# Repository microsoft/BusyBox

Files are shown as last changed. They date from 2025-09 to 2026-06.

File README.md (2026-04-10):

# BusyBox: Benchmarking Affordance Generalization

BusyBox is a physical 3D-printable device for benchmarking affordance generalization in robot foundation models.

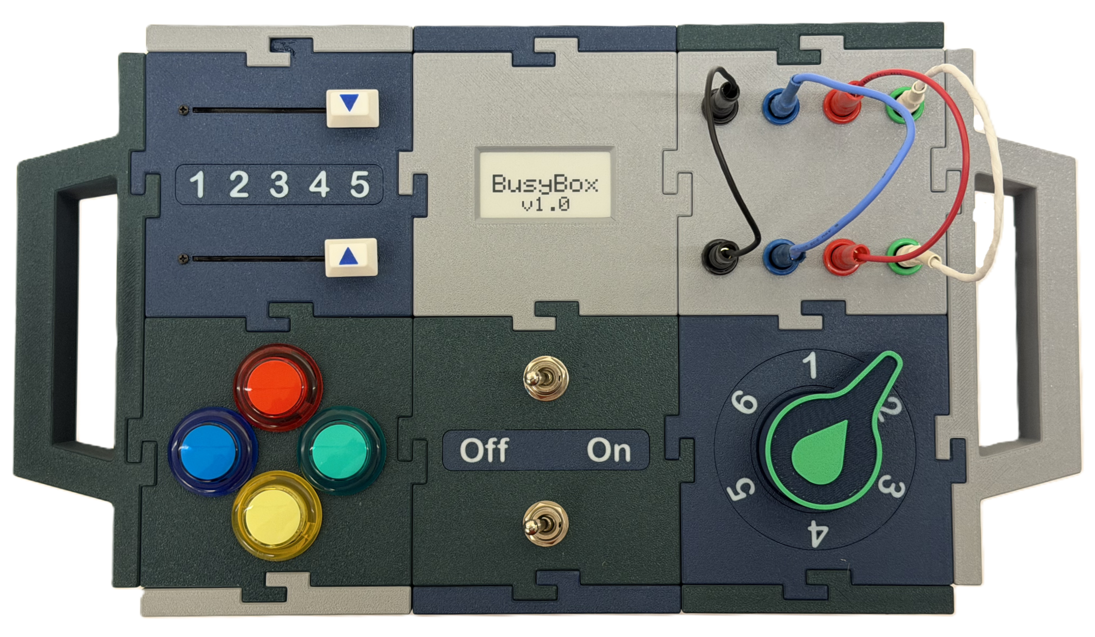
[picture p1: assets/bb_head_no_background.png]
busybox_assembled


It features

 - Modular design with 6 interchangeable modules (buttons, switches, sliders, wires, knob, and display)  
 - Open-source CAD files and bill of materials for easy reproduction  
 - Optional electronics and Raspberry Pi instrumentation for automated state logging  
 - Reconfigurable setups enabling systematic evaluation of generalization  
 - A language-annotated dataset of 1000+ demonstration trajectories oof BusyBox affordances  

Please check out our [website](https://microsoft.github.io/BusyBox/) for more details.

## BusyBox assembly instructions

For fully building a instrumented BusyBox capable of state logging, see the [BOM](BOM.md).

First print the BusyBox following [Printing Instructions](cad/printing_instructions.md) with details on files to print and any details on print settings.

## Electronic Assembly:

TODO: add instructions on how to assemble electronics with pictures

## Firmware Flashing:

Instructions for flashing the Arduino Nano's firmware: [Flashing Firmware](devices/flashing_firmware.md)

## Data Collection

See [Data Collection](assets/taskbox_data_collection.docx) for details on our data collection methodology.

### Recording Episodes with Aloha

The `robots/aloha/` directory contains a complete data recording pipeline for collecting teleoperated demonstrations using the [Aloha](https://github.com/tonyzhaozh/aloha) bimanual robot.

#### Prerequisites

- Aloha robot hardware (leader + follower arms) set up and calibrated
- USB foot pedal for episode control
- (Optional) Instrumented BusyBox with MQTT bridge for state logging

#### Quick Start

```bash
pip install -r requirements.txt
python robots/aloha/record_busybox_episodes.py
```

#### Foot Pedal Controls

| Pedal | Action |
|---|---|
| Left | Start recording |
| Middle | Stop and save episode / Refresh task prompt |
| Right | Pause/resume teleop / Reject recording |

#### Configuration

Edit `robots/aloha/utils/config.py` to set:
- `dataset_dir` — where episodes are saved
- `camera_names` — which cameras to record
- `using_instrumented_busybox` — enable MQTT state logging

#### Episode Data Format (HDF5)

Each episode is saved as an HDF5 file with:
- `/observations/qpos` — joint positions (14,) per timestep
- `/observations/qvel` — joint velocities (14,)
- `/observations/effort` — joint torques (14,)
- `/observations/images/{cam_name}` — JPEG-compressed camera frames
- `/action` — leader arm joint commands (14,)
- `/observations/timestamp`, `/action_timestamp` — timing data

#### Utility Scripts

| Script | Purpose |
|---|---|
| `scripts/count_episodes_collected_today.py` | Count episodes recorded in the current session |
| `scripts/busybox_calibration.py` | BusyBox sensor calibration |
| `scripts/visualize_hdf5.ipynb` | Visualize recorded episode data |
| `robots/aloha/eval_rollouts.py` | Evaluate policy rollouts |

### Raspberry Pi MQTT Bridge

For instrumented BusyBox setups, the `devices/pi_sw/` directory contains the MQTT bridge that runs on the Raspberry Pi:

```bash
# On the Raspberry Pi
pip install pyserial paho-mqtt
python devices/pi_sw/mqtt_bridge.py --broker-host <MQTT_BROKER_IP>
```

See [Flashing Firmware: Installing MQTT on the Pi](devices/flashing_firmware.md#6-installing-mqtt-on-the-pi) for setup details.

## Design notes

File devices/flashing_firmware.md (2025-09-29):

# Setting up Raspberry Pi Zero W for flashing BusyBox firmware

### 1. Install OS
Install [Raspberry Pi OS (64-bit)](https://www.raspberrypi.com/software/operating-systems/) on [Pi Zero 2 W](https://www.raspberrypi.com/products/raspberry-pi-zero-2-w/). 

### 2. Acquire Hardware
required hardware:
 - Enough USB hubs to flash all BusyBox Modules desired (for 6 modules, this requires 6 Nanos and 2 4-port USB Hubs).
 - internet connection for Pi Zero 2 W

### 3. Install and Initialize Arduino CLI

install
```bash
curl -fsSL https://raw.githubusercontent.com/arduino/arduino-cli/master/install.sh | sh
sudo mv bin/arduino-cli /usr/local/bin/
rm -rf bin
```

initialize 
```bash
arduino-cli config init
arduino-cli core update-index
arduino-cli core install arduino:avr
# e-ink display drivers
arduino-cli lib update-index
arduino-cli lib install "GxEPD2"
```

### 4. Build and Upload firmware code to Arduinos

Plug in USB Hubs to the Pi Zero 2 W. This requires one USB Hub to be daisy chained to the other.

Plug in the targeted number of Arduinos to the Pi Zero 2 W's USB Hubs.

```bash
cd BusyBox/devices
ls /dev/ttyUSB* -la  # view connected Arduino Nanos
nano device_build_targets.yaml  # edit device ports and module targets as needed
./build_all.sh
./upload_all.sh
```

### 5. Verify firmware

View serial output of arduinos:
```bash
# replace /dev/ttyUSB0 with the device you want to view
screen /dev/ttyUSB0 9600
# Exit: `Ctrl+A` then `K` → `Y`.
```

If using the E-ink display module, send e-ink commands:
```bash
# assuming /dev/ttyUSB5 corresponds to the e-ink module
stty -F /dev/ttyUSB5 9600 cs8 -cstopb -parenb
echo -e "1:Hello\n" > /dev/ttyUSB5  # set top line
echo -e "2:World\n" > /dev/ttyUSB5  # set bottom line
```

test port identification of modules
```bash
cd BusyBox/devices
python test_identify_arduinos.py
```

this should return:
```
Detected Arduino modules:
PORT          MODULE
------------  --------------------
/dev/ttyUSB0  buttons_module
/dev/ttyUSB1  knob_module
/dev/ttyUSB2  sliders_module
/dev/ttyUSB3  switches_module
/dev/ttyUSB4  wires_module
/dev/ttyUSB5  e-ink_display_module
```

### 6. Installing MQTT on the pi
```bash
sudo apt update
sudo apt install -y mosquitto mosquitto-clients
sudo systemctl enable mosquitto
sudo systemctl start mosquitto
# Check status:
systemctl status mosquitto

sudo apt install python3-paho-mqtt
```

running the mqtt bridge
```bash
cd BusyBox/devices/pi_sw
python mqtt_bridge.py --broker-host localhost  # MQTT broker on pi
python mqtt_bridge.py --broker-host 10.137.70.35  # MQTT broker on other PC

# command the e-ink display:
mosquitto_pub -t busybox/eink/cmd -m "1:BusyBox Demo"
mosquitto_pub -t busybox/eink/cmd -m "2:Ready!"

# listen to published topic chatter
mosquitto_sub -h localhost -t 'busybox/buttons/state' -v  # replace `buttons` with desired state
```

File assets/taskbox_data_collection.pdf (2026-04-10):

# Taskbox Data Collection Guide

There are surprisingly so many ways to push a button, pull a wire, and move a slider. Variations include trajectory taken, which arm was used, starting point, ending point, movement speed, etc. This guide is meant to unify how data is collected so models have high quality demonstrations useful for finetuning.

This guide is specifically relating to collecting data by teleoperating the Mobile Aloha to collect demonstrations on accomplishing tasks on the taskbox.

General rules and task specific rules for robot operators follow.

## General rules

1. Be efficient with movement. Demonstrations should take no longer than 15 seconds.
2. Keep moving. Demonstrations should be active, only remain still when something dynamic is happening (i.e. dropping a wire).
3. End a session when task has been completed. There is no need to return to a neutral position.
4. Start from different initial positions before recording. These starting positions fall between the starting home position and somewhere above the box.
5. Ensure both wrist cameras have a view of the task at hand.
6. Follow pre-recording instructions that set the initial state of the taskbox, the pose of the taskbox, and the starting position of the arm.

## Specific rules

Here is the taskbox:

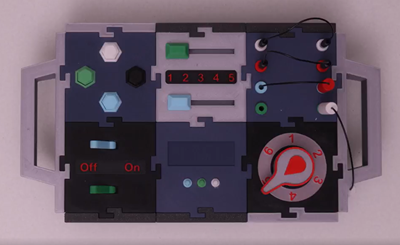
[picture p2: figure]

from top left to bottom right the modules are as follows: buttons, slider, wires, switches, display, and knob

Button Module

With grippers closed, move to press the button with one gripper and have the other arm’s camera viewing the action. End recording just after button is released and the gripper is a few inches above the button. If the button press was missed, retry at most once before ending the recording.

Slider Module

With grippers closed, move the slider by pushing it one direction or another. If the value is overshot, correct the overshoot and end the recording. The other arm’s camera should have visual.

Wires Module

When pulling a wire, only pull the bottom terminal or the right terminal based on module orientation. After pulling the wire out of the terminal, leave the other end in place.

When inserting a wire, it may be required to move the wire in a more favorable position before recording so the demonstration does not exceed 15 seconds.

Switch module

Brace the box by holding the handle with one gripper and move the switch to the desired position with the other gripper.

Knob Module

With grippers closed, one gripper will nudge the knob until it is in the desired position and the other will view with its camera. If the target is overshot, just nudge in the other direction.

## Pre recording instructions

Before recording an episode a prompt will ask the operator to move the robot to a certain position and angle on the table, set the state of sliders, wires, switches, and knob, and request a general starting position for the arm between home position and taskbox.

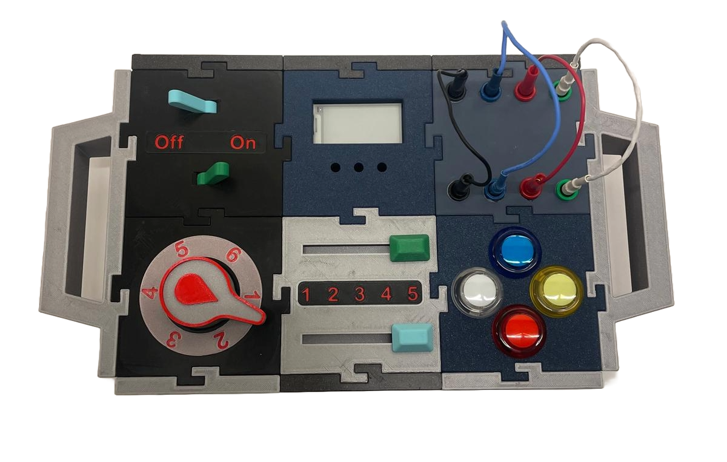
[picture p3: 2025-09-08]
assets/shuffled_box_config_1_background_removed.png

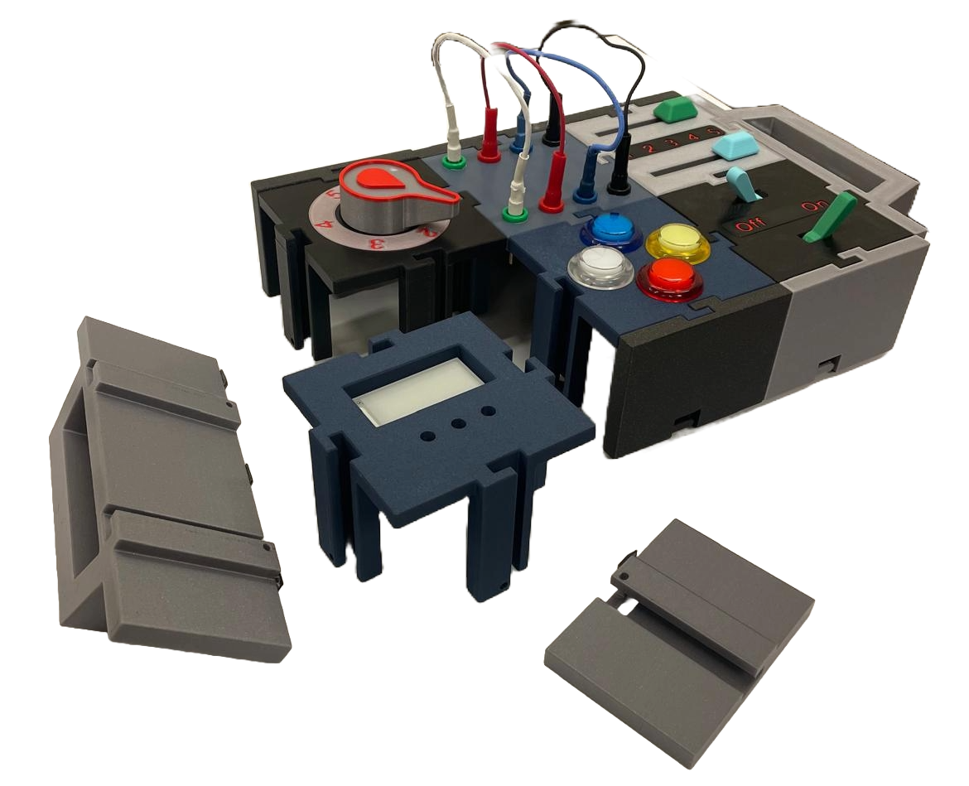
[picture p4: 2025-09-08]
assets/taskbox_disasembled.png

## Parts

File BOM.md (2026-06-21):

# Bill of Materials

### Fully Instrumented BusyBox parts
| Item | Quantity | Price per item | Link |
|---|---|---|---|
| Nano with USB Cable x 3 | 2 | $15.99 | [Amazon Link](https://www.amazon.com/dp/B07G99NNXL/ref=ox_ya_os_product) |
| Rotary Encoder Module x 2 | 1 | $6.99 | [Amazon Link](https://www.amazon.com/dp/B0D2TTG858/ref=ox_ya_os_product) |
| Toggle Rocker Switch - 2 Pin SPST x 2 | 1 | $7.99 | [Amazon Link](https://www.amazon.com/dp/B07T6XWZKN/ref=ox_ya_os_product?th=1) |
| 10K Double Linear Slide Potentiometer 75MM x 10 | 1 | $11.99 | [Amazon Link](https://www.amazon.com/dp/B09NX39NWR/ref=ox_ya_os_product) |
| 20 PCS 4mm Banana Socket Plug Binding Post Banana Female Plug Jack Connector | 1 | $11.49 | [Amazon Link](https://www.amazon.com/dp/B07KJX4G46/ref=ox_ya_os_product) |
| 40 Pieces 4 mm Banana Plugs, Gold Plated Banana Plug Connector (5 Color) | 1 | $9.49 | [Amazon Link](https://www.amazon.com/dp/B07ZP7GCYR) |
| 5X 30mm Arcade LED Lights Push Button Built-in Switch 5V Illuminated Buttons | 1 | $11.88 | [Amazon Link](https://www.amazon.com/dp/B01N11BDX9/ref=ox_ya_os_product) |
| Raspberry Pi Zero 2 W | 1 | $23.71 | [Amazon Link](https://www.amazon.com/dp/B09LH5SBPS) |
| Waveshare 4 Port USB HUB HAT | 2 | $16.99 | [Amazon Link](https://www.amazon.com/dp/B06Y2TSR1D) |
| Waveshare 250x122, 2.13inch E-Ink display HAT for Raspberry Pi| 1 | $14.99 | [Waveshare Link](https://www.waveshare.com/2.13inch-e-paper-hat.htm) |
| Portable Battery Bank | 1 | $21.99 | [Amazon Link](https://www.amazon.com/dp/B09Y5QPYQH) |

> *Note: Portable battery bank dimensions: `133 x 70 x 15 mm`*

Total Cost: $164.49 (pre-tax)

---
### Minimal Required Build (No electronic instrumentation)
| Item | Quantity | Price per item | Link |
|---|---|---|---|
| Rotary Encoder Module x 2 | 1 | $6.99 | [Amazon Link](https://www.amazon.com/dp/B0D2TTG858/ref=ox_ya_os_product) |
| Toggle Rocker Switch - 2 Pin SPST x 2 | 1 | $7.99 | [Amazon Link](https://www.amazon.com/dp/B07T6XWZKN/ref=ox_ya_os_product?th=1) |
| 10K Double Linear Slide Potentiometer 75MM x 10 | 1 | $11.99 | [Amazon Link](https://www.amazon.com/dp/B09NX39NWR/ref=ox_ya_os_product) |
| 20 PCS 4mm Banana Socket Plug Binding Post Banana Female Plug Jack Connector | 1 | $11.49 | [Amazon Link](https://www.amazon.com/dp/B07KJX4G46/ref=ox_ya_os_product) |
| 40 Pieces 4 mm Banana Plugs, Gold Plated Banana Plug Connector (5 Color) | 1 | $9.49 | [Amazon Link](https://www.amazon.com/dp/B07ZP7GCYR) |
| 5X 30mm Arcade LED Lights Push Button Built-in Switch 5V Illuminated Buttons | 1 | $11.88 | [Amazon Link](https://www.amazon.com/dp/B01N11BDX9/ref=ox_ya_os_product) |

Total Cost: $59.83 (pre-tax)

---
### Additional Assembly Materials

 - Solder
 - Flux
 - DuPont connectors
 - ~20 AWG multicolored wire for connecting different components
 - Hot Glue for affixing wires and Arduino Nanos to each module

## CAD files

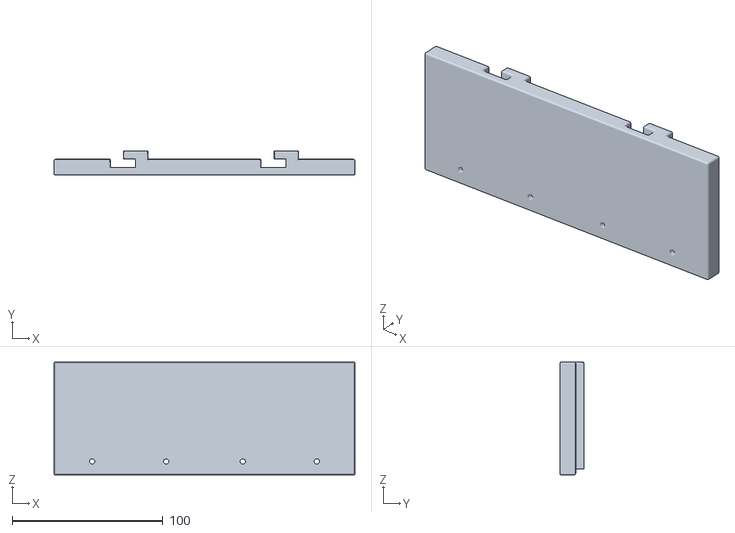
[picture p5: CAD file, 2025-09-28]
cad/BusyBoxCad/Box_Frame/Double_Side.stl
199.9 x 16.0 x 75.0

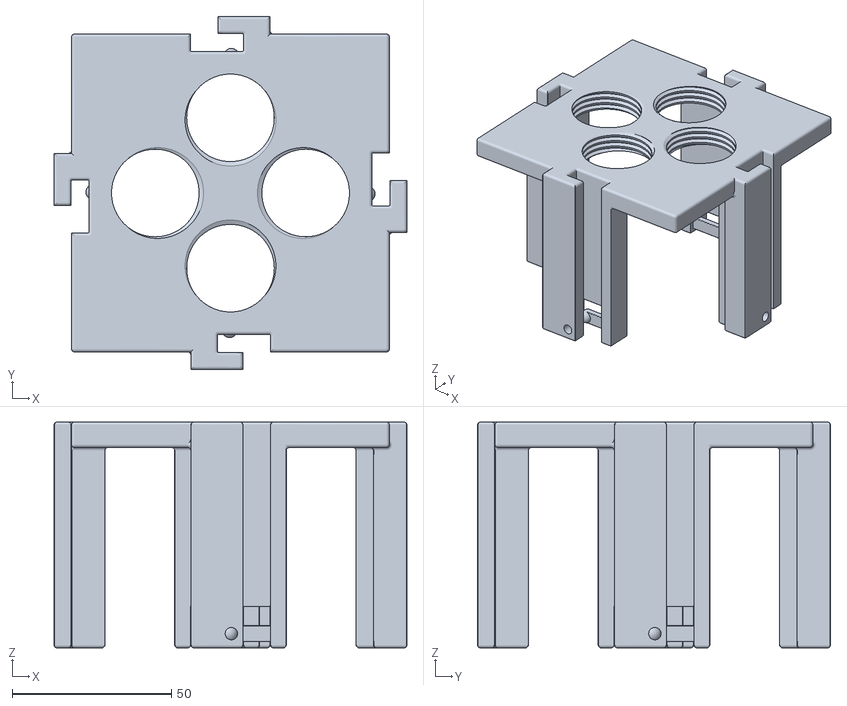
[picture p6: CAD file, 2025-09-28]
cad/BusyBoxCad/Button_Box.stl
110.9 x 110.9 x 71.0

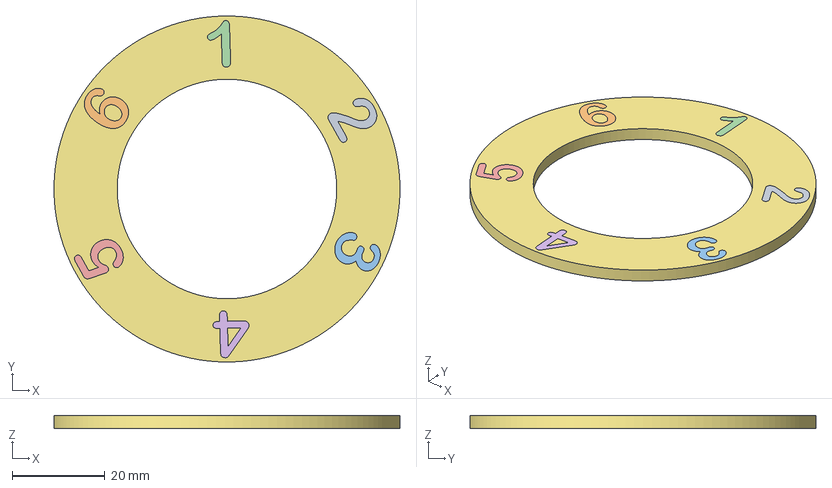
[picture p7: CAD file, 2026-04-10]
cad/BusyBoxCad/Knob_Module/Rotary_Text_Multicolor.3mf
74.5 x 74.5 x 2.70 mm
Ring Text

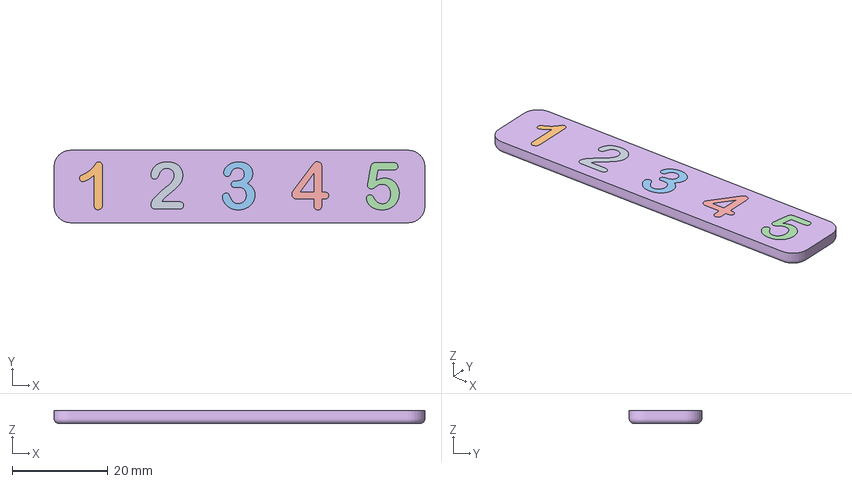
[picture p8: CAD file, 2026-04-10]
cad/BusyBoxCad/Slider_Module/Slider_Text.3mf
77.6 x 15.2 x 2.70 mm
Slider Text

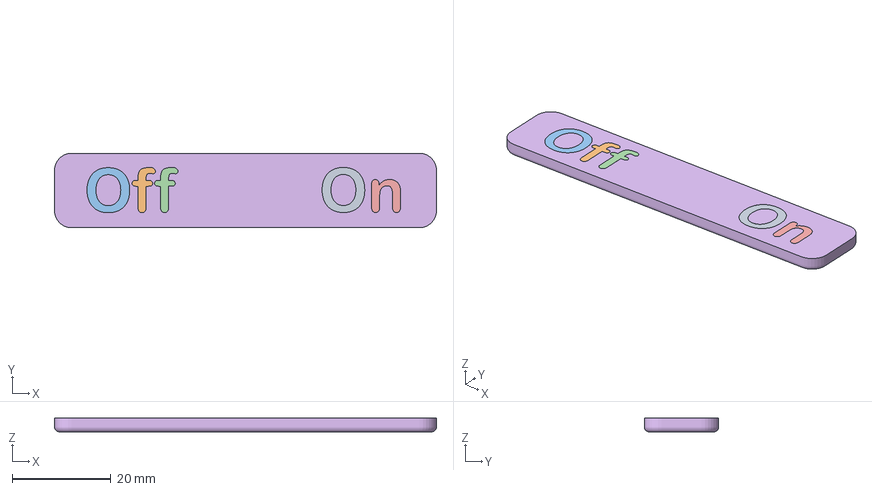
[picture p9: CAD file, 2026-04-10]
cad/BusyBoxCad/Switch_Module/Switch_Text_Multicolor.3mf
77.5 x 15.1 x 2.80 mm
Switch Text

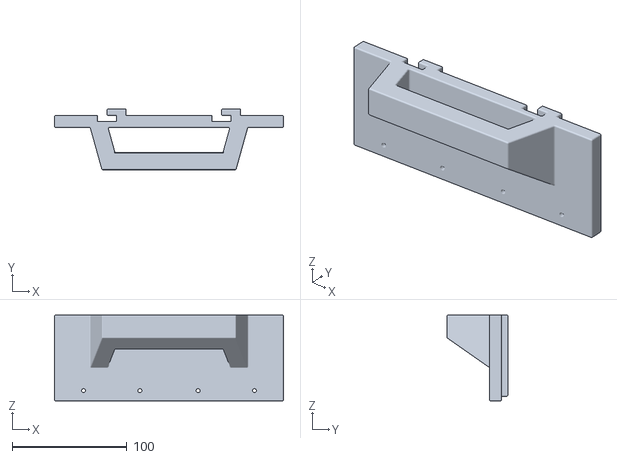
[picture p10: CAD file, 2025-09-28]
cad/BusyBoxCad/Box_Frame/Handle.stl
199.9 x 53.0 x 75.0

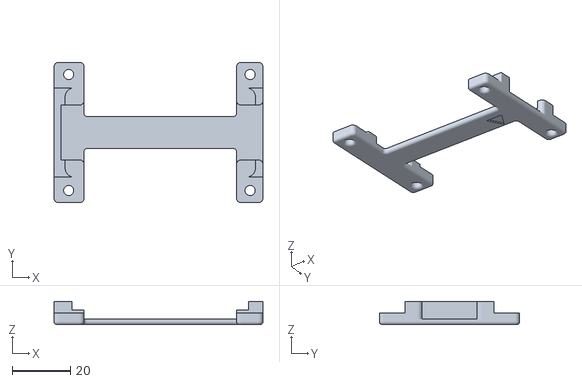
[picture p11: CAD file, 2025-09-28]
cad/BusyBoxCad/Display_Module/Display_Holder.stl
72.0 x 48.3 x 8.00

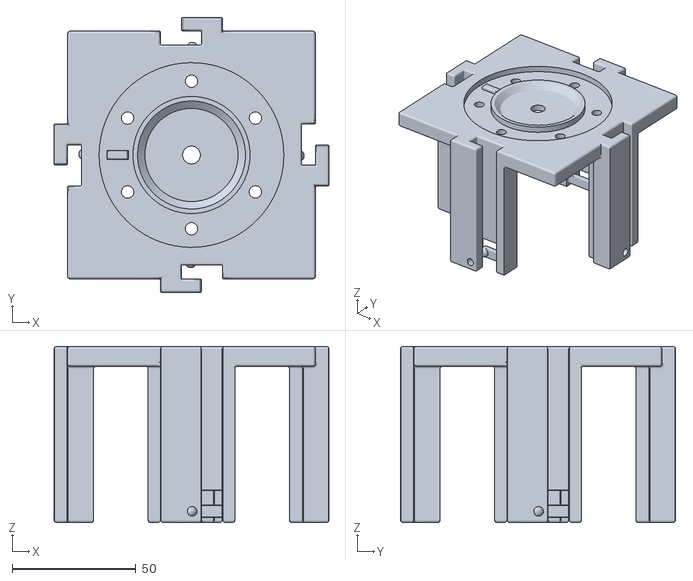
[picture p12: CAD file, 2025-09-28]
cad/BusyBoxCad/Knob_Module/Rotary_Box.stl
110.9 x 110.9 x 71.0

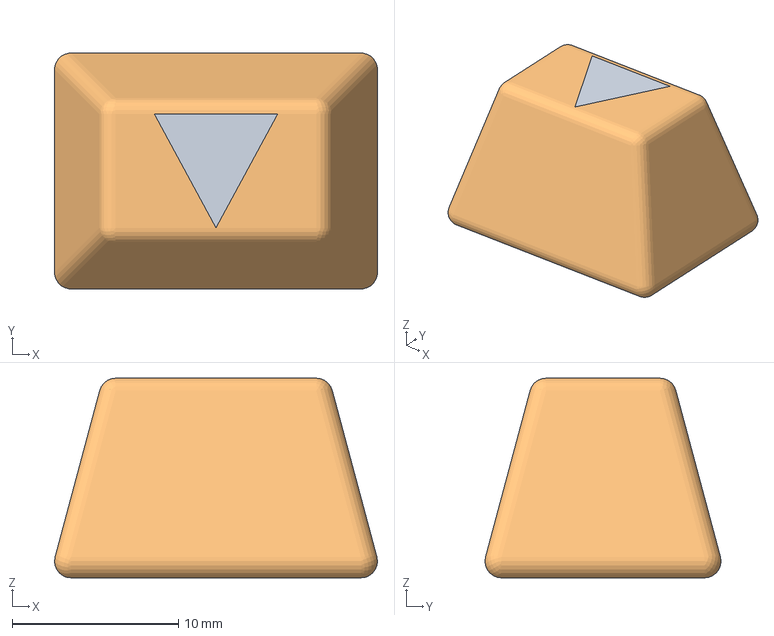
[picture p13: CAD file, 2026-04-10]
cad/BusyBoxCad/Slider_Module/Slider_Knobs_Multicolor.3mf
19.4 x 14.2 x 12.0 mm
Slider Knob

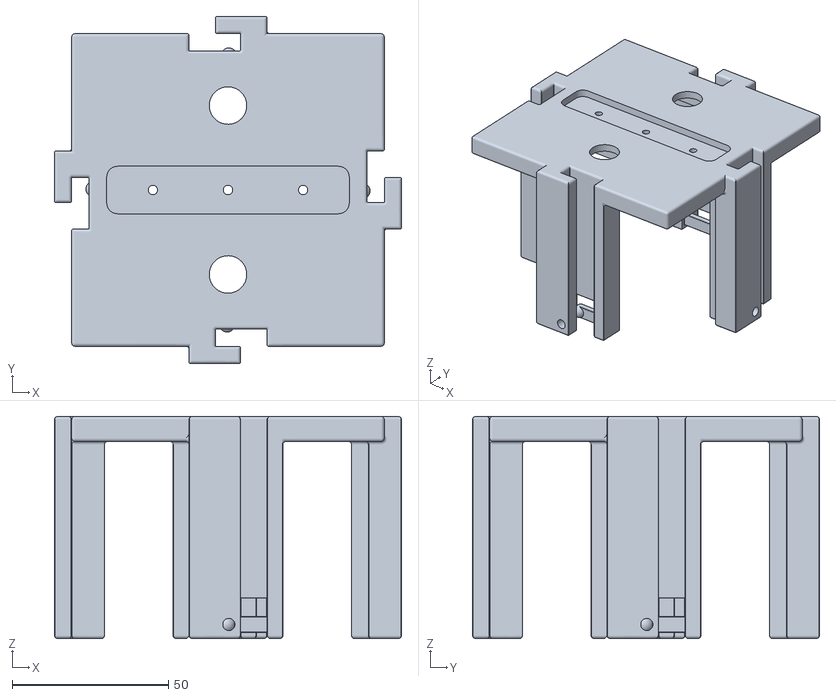
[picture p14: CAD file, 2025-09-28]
cad/BusyBoxCad/Switch_Module/Switch_Box.stl
110.9 x 110.9 x 71.0

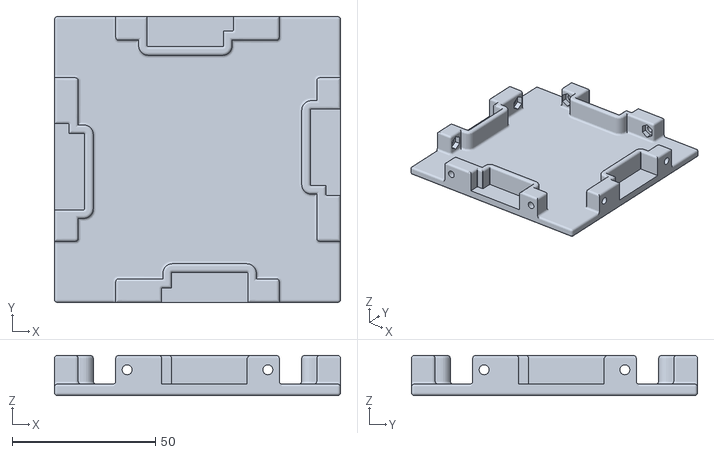
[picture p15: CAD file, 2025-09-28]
cad/BusyBoxCad/Box_Frame/Box_Bottom.stl
100.0 x 100.0 x 14.0

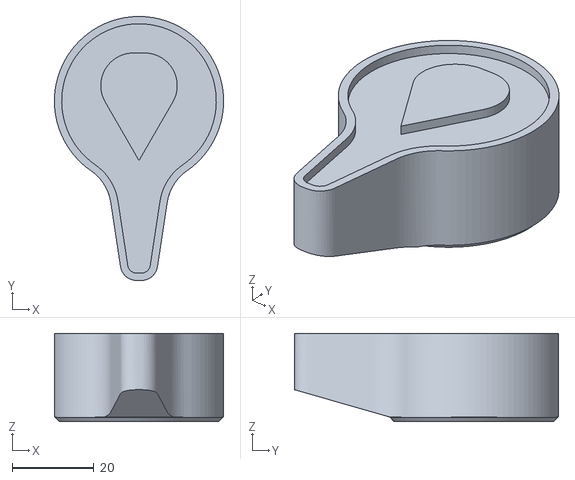
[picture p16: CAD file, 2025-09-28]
cad/BusyBoxCad/Knob_Module/Rotary_Knob.stl
41.5 x 64.7 x 21.6

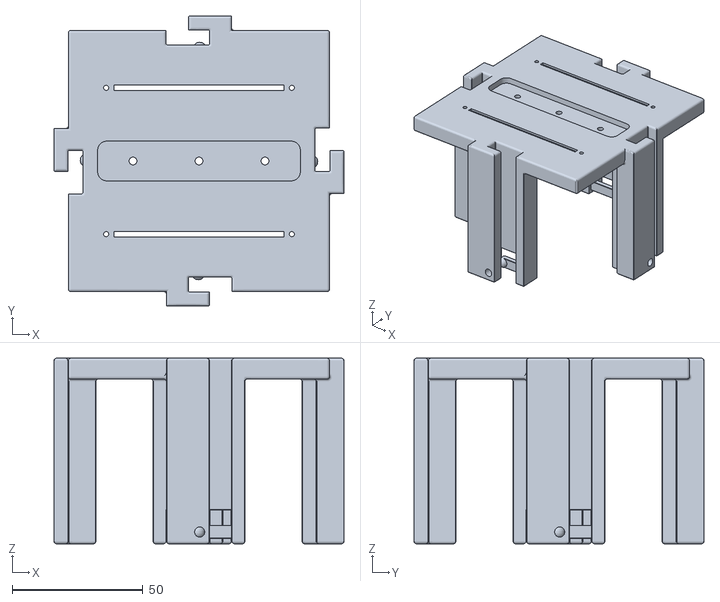
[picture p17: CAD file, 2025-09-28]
cad/BusyBoxCad/Slider_Module/Slider_Box.stl
110.9 x 110.9 x 71.0

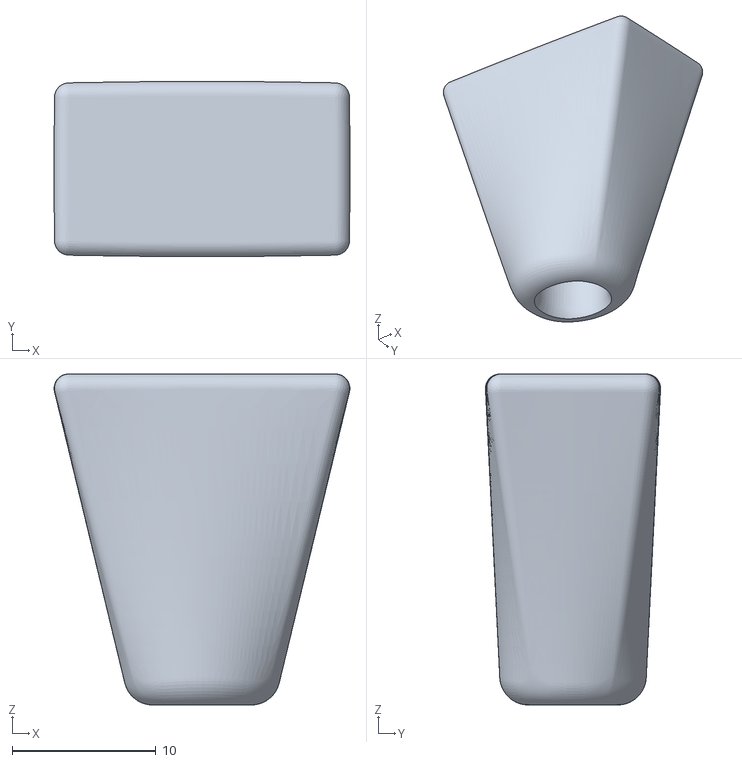
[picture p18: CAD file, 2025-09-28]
cad/BusyBoxCad/Switch_Module/Switch_Cover.stl
20.6 x 12.2 x 23.0

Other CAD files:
cad/BusyBoxCad/Display_Module/Display_Box.stl
cad/BusyBoxCad/Blank_Module.stl
cad/BusyBoxCad/Wire_Module.stl
cad/BusyBoxCad/Box_Frame/Single_Side.stl

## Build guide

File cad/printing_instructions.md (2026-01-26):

# Printing Guide

For our prints we used the Bambu P1S with the Bambu Studio.

We used standard Bambu filament with the default printing presets and using Tree supports.

Some of our prints utilize the "Multi-Color Printing" feature on the Bambu P1S.

## Recipe for printing canonical BusyBox configuration

All meshes exist at `BusyBox/cad/BusyBoxCad` and the solid model exists at `BusyBox/cad/task_box.step`.

Each of the following are printed individually with different filaments colors:

| Part Type | BusyBox Part | Number of Items | Multi-color |
|---|---|---|---|
| Box_Frame | Box_Bottom.stl | 6 | no |
| - | Single_side.stl | 6 | no |
| - | Handle.stl | 2 | no |
| Button_Module | Button_Box.stl | 1 | no |
| Display_Module | Display_Box.stl | 1 | no |
| - | Display_Holder.stl | 1 | no |
| Knob_Module | Rotary_Box.stl | 1 | no |
| - | Rotary_Knob.stl | 1 | no |
| - | Rotary_Text_Multicolor.3mf | 1 | yes |
| Slider_Module | Slider_Box.stl | 1 | no |
| - | Slider_Knobs_Multicolor.3mf  | 2 | yes |
| - | Slider_Text.3mf | 1 | yes |
| Switch_Module | Switch_Box.stl | 1 | no |
| - | Switch_Text_Multicolor.3mf | 1 | yes |
| Wire_Module | Wire_Module.stl | 1 | no |

## Tips

 - print the "box" parts with the faceplate on the printing bed.

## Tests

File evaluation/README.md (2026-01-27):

# bbx_eval

Evaluation harness for running BusyBox task rollouts on **Mobile ALOHA** (real robot) and logging results.

This folder contains a small, opinionated “human-in-the-loop” evaluator:
- It **launches one or more robot policy clients** (via shell commands),
- Presents a task prompt + required initial BusyBox state,
- Optionally records a webcam video,
- Asks a human to mark **success/fail** and add notes,
- Writes a running tally to a JSON results file.

> Important: **`bbx_eval_config.yaml` and `eval_bbx_client.py` are custom to our lab’s Mobile ALOHA + BusyBox setup.**
> Other researchers should treat this as a *reference implementation* and adapt:
> - robot bringup and reset (“opening ceremony”),
> - how tasks are sent to their client(s),
> - camera/video capture,
> - and any safety/timeouts.

---

## Files

- `generate_task_eval_list.py`: creates a randomized evaluation list in `eval_rollouts.json`.
- `bbx_eval_config.yaml`: evaluation config (timeouts, video recording, and how clients are launched).
- `eval_bbx_client.py`: main evaluation loop (reads rollouts, runs clients, records videos, prompts for labels).

---

## Quickstart (general flow)

### 1) Generate an evaluation rollout list

From this directory:

```bash
cd /home/aloha/dean/bbx_eval
python3 generate_task_eval_list.py
```

This writes `eval_rollouts.json` with:
- `meta`: info like seed and number of tasks
- `eval_rollouts`: a shuffled list of tasks
  - `task_prompt` / `task_category` / `target`
  - `init_box_state`: the BusyBox state you should set before running the task

If you want a different mix of tasks or counts, edit the parameters near the bottom of `generate_task_eval_list.py` (seed, task types, samples per task).

### 2) Configure evaluation settings + client launch commands

Edit `bbx_eval_config.yaml`:

- **General**
  - `DRY_RUN`: if `true`, skips actually launching clients (still walks through prompts)
  - `TASK_TIMEOUT`: prompt timeout passed through to the clients (per-task)

- **Video**
  - `RECORD_VIDEOS`: enable/disable webcam capture
  - `VIDEO_DEVICE_INDEX`: OpenCV camera index (often `0`)

- **Paths**
  - `TASK_EVAL_LIST_PATH`: usually `eval_rollouts.json`
  - `OUTPUT_JSON_PATH`: output results file (e.g. `eval_results.json`)

- **Robot**
  - `SLEEP_COMMAND`: command to put the robot in a safe state before starting (lab-specific)

- **Clients**
  - `CLIENTS_TO_EVALUATE`: a list of named clients, each specified as a shell command string.

### 3) Run the evaluator

```bash
cd /home/aloha/dean/bbx_eval
python3 eval_bbx_client.py
```

What you’ll see:
1. A prompt to place the BusyBox in the configured initial pose.
2. (Optional) It loads `OUTPUT_JSON_PATH` if it exists to **resume** from the saved `index`.
3. It prints configured clients and asks you to run **one client** or **all**.
4. For each rollout:
   - It prints the task prompt.
   - It prints the required initial BusyBox state (sliders, wires, switches, knob).
   - It launches the selected client(s) for that task.
   - It asks you to mark success/fail and optionally enter notes.

Outputs:
- Results JSON written to `OUTPUT_JSON_PATH` with keys:
  - `tally`: per-client and per-task-category counts
  - `notes`: per-trial annotations (prompt, category, success, freeform notes)
  - `index`: resume pointer
  - `meta`: session metadata (timestamp, models, etc.)
- Videos (if enabled) saved under `eval_videos/` with filenames like:
  - `<taskIndex>_<clientName>_<taskCategory>_<timestamp>_<True|False>.mp4`

---

## Notes on customization (for other robots / labs)

This code is **not a general-purpose evaluation framework**. It assumes:
- **Mobile ALOHA** hardware and a specific bringup/reset routine.
- Policy clients that can accept a natural-language task prompt with a timeout.
- A local webcam accessible via OpenCV for recording.

To adapt elsewhere, you’ll likely want to modify:
- `perform_opening_ceremony()` in `eval_bbx_client.py` (robot reset / safe pose).
- Client command invocation + CLI flags (how tasks are transmitted).
- Video recording (device selection, framerate, resolution, multi-camera, etc.).
- Safety: e-stops, timeouts, collision constraints, and failure handling.

---

## Troubleshooting

- **Camera won’t open**: set `VIDEO_DEVICE_INDEX` to the correct camera, or set `RECORD_VIDEOS: false`.
- **Client doesn’t receive the prompt**: verify your `CLIENTS_TO_EVALUATE` command runs standalone, then confirm the appended flags match your client’s CLI.
- **Resume behavior**: if `OUTPUT_JSON_PATH` exists, evaluation resumes from its saved `index`. Delete/rename the file to start fresh.

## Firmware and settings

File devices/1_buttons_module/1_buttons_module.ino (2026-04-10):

/*
  nano_input_change_debounce_binary.ino
  Reads D2..D5, debounces each input, and prints all 4 states (1 for HIGH, 0 for LOW)
  whenever any debounced state changes.

  Config:
    USE_INTERNAL_PULLUPS  - set true to enable INPUT_PULLUP (switch to GND).
    DEBOUNCE_MS           - debounce period (ms).
    POLL_INTERVAL_MS      - how often the loop polls inputs (ms).

  Note:
    - If USE_INTERNAL_PULLUPS = true, switches to GND will read LOW when closed
      (so "pressed" will be 0). The sketch prints raw pin values as 1 (HIGH) / 0 (LOW).
*/

const bool USE_INTERNAL_PULLUPS = true; // true -> INPUT_PULLUP (active = LOW when switch to GND)
const unsigned long DEBOUNCE_MS = 50;   // debounce time in ms
const unsigned long POLL_INTERVAL_MS = 5; // sampling interval in ms


const uint8_t inputPins[] = {2, 3, 4, 5};
const uint8_t outputPins[] = {6, 7, 8, 9};
const uint8_t NUM_PINS = sizeof(inputPins) / sizeof(inputPins[0]);

// Heartbeat (on-board LED) pattern: 1 distinct flash separated by an OFF beat
// We enforce at least one OFF after the flash so it is visible (cycle length 2 beats here)
const uint8_t HB_FLASHES = 1; // number of flashes per cycle
const unsigned long HB_BEAT_MS = 500; // 2 Hz beat period
const uint8_t HB_CYCLE_BEATS = (HB_FLASHES == 1) ? 2 : (uint8_t)(HB_FLASHES * 2 - 1); // ensure an OFF follows single flash
const unsigned long HB_CYCLE_PAUSE_MS = 1500; // extra OFF pause after full pattern
uint8_t hbBeatIndex = 0; // 0..HB_CYCLE_BEATS-1
unsigned long hbNextBeatDueMs = 0; // scheduling timestamp

uint8_t lastReading[NUM_PINS];
uint8_t stableState[NUM_PINS];
unsigned long lastEdgeTime[NUM_PINS];

// For LED hold logic
unsigned long ledHoldUntil[NUM_PINS] = {0, 0, 0, 0};

// --- Alive beacon via shared header (DRY) ---
#define MODULE_NAME "buttons_module"
#include <alive_beacon.h>

// Alive beacon data line: current button states
void beaconData() {
  Serial.print(F("Button States: "));
  for (uint8_t i = 0; i < NUM_PINS; ++i) {
    Serial.print('D'); Serial.print(inputPins[i]); Serial.print('=');
    Serial.print(stableState[i] == HIGH ? '1' : '0');
    if (i < NUM_PINS - 1) Serial.print(' ');
  }
  Serial.println();
}

void setup() {
  Serial.begin(9600);
  pinMode(LED_BUILTIN, OUTPUT);
  digitalWrite(LED_BUILTIN, LOW);

  for (uint8_t i = 0; i < NUM_PINS; ++i) {
    pinMode(inputPins[i], USE_INTERNAL_PULLUPS ? INPUT_PULLUP : INPUT);
    pinMode(outputPins[i], OUTPUT);
    lastReading[i] = digitalRead(inputPins[i]);
    stableState[i] = lastReading[i];
    lastEdgeTime[i] = millis();
    digitalWrite(outputPins[i], LOW); // Start with LEDs off
    ledHoldUntil[i] = 0;
  }

  Serial.println(F("Starting input monitor (D2..D5) - output 1=HIGH, 0=LOW"));
  Serial.print(F("USE_INTERNAL_PULLUPS="));
  Serial.println(USE_INTERNAL_PULLUPS ? F("true (active=LOW)") : F("false (active=HIGH)"));
  Serial.print(F("DEBOUNCE_MS="));
  Serial.println(DEBOUNCE_MS);
  printStates();

  // Initialize alive beacon AFTER initial informational prints so identity beacons are clean
  setAliveDataPrinter(beaconData);
  initAliveBeacon();
}

void loop() {
  bool anyChanged = false;
  unsigned long now = millis();

  // Periodic identity message (non-blocking)
  runAliveBeacon();


  for (uint8_t i = 0; i < NUM_PINS; ++i) {
    uint8_t r = digitalRead(inputPins[i]);
    if (r != lastReading[i]) {
      lastEdgeTime[i] = now;
      lastReading[i] = r;
    } else {
      if ((now - lastEdgeTime[i]) >= DEBOUNCE_MS && r != stableState[i]) {
        stableState[i] = r;
        anyChanged = true;
      }
    }

    // LED logic: illuminate while pressed, and for 1s after release, reset timer if pressed again
    bool pressed = (USE_INTERNAL_PULLUPS ? (stableState[i] == LOW) : (stableState[i] == HIGH));
    if (pressed) {
      digitalWrite(outputPins[i], HIGH);
      ledHoldUntil[i] = now + 1000; // 1 second hold after release
    } else {
      if (now < ledHoldUntil[i]) {
        digitalWrite(outputPins[i], HIGH);
      } else {
        digitalWrite(outputPins[i], LOW);
      }
    }
  }

  if (anyChanged) {
    printStates();
  }

  delay(POLL_INTERVAL_MS);

  // Heartbeat update with extended pause after cycle
  if (now >= hbNextBeatDueMs) {
    bool on = (hbBeatIndex % 2 == 0) && ((hbBeatIndex / 2) < HB_FLASHES);
    digitalWrite(LED_BUILTIN, on ? HIGH : LOW);
    hbBeatIndex++;
    if (hbBeatIndex >= HB_CYCLE_BEATS) {
      // End of pattern: force OFF and insert long pause
      digitalWrite(LED_BUILTIN, LOW);
      hbBeatIndex = 0;
      hbNextBeatDueMs = now + HB_CYCLE_PAUSE_MS;
    } else {
      hbNextBeatDueMs = now + HB_BEAT_MS;
    }
  }
}

void printStates() {
  // Example: States: D2=1 D3=0 D4=1 D5=1
  Serial.print(F("Button States: "));
  for (uint8_t i = 0; i < NUM_PINS; ++i) {
    Serial.print('D');
    Serial.print(inputPins[i]);
    Serial.print('=');
    Serial.print(stableState[i] == HIGH ? '1' : '0');
    if (i < NUM_PINS - 1) Serial.print(' ');
  }
  Serial.println();
}

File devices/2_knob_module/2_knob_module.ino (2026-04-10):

/*
    KY-040 Rotary Encoder Basic Example
    - Detects rotation direction and steps
    - Detects button press
    - Prints events to Serial
  
    Pinout (typical):
        CLK (A) -> D2
        DT  (B) -> D3
        SW      -> D4
        VCC     -> 5V
        GND     -> GND
*/

const int pinCLK = 2; // A (CLK)
const int pinDT  = 3; // B (DT)
const int pinSW  = 4; // Switch
// Heartbeat: 2 distinct flashes (ON-OFF-ON) then idle pauses
const uint8_t HB_FLASHES = 2; // number of flashes
const unsigned long HB_BEAT_MS = 500; // 2 Hz
// Distinct flashes need an OFF between each; minimal beats = flashes*2 -1; add at least 2 OFF beats tail
const uint8_t HB_MIN_BEATS = (uint8_t)(HB_FLASHES * 2 - 1);
const uint8_t HB_TAIL_OFF = 2; // extra OFF beats to improve identification spacing
const uint8_t HB_CYCLE_BEATS = HB_MIN_BEATS + HB_TAIL_OFF; // ON OFF ON OFF OFF for 2 flashes
const unsigned long HB_CYCLE_PAUSE_MS = 1500; // long OFF pause after pattern
uint8_t hbBeatIndex = 0; // 0..HB_CYCLE_BEATS-1
unsigned long hbNextBeatDueMs = 0; // scheduler timestamp


int lastState = 0;
int lastSW = HIGH;
long encoderValue = 0;

bool DEBUG = false;

// State machine lookup table for quadrature decoding
// Each entry: [old_AB << 2 | new_AB] => -1, 0, or +1
const int8_t enc_states[] = {0, -1, 1, 0,
                             1, 0, 0, -1,
                            -1, 0, 0, 1,
                             0, 1, -1, 0};


// Alive beacon
#define MODULE_NAME "knob_module"
#include <alive_beacon.h>

void beaconData() {
    Serial.print(F("Knob State: "));
    Serial.println(encoderValue);
}

void setup() {
    Serial.begin(9600);
    pinMode(pinCLK, INPUT_PULLUP);
    pinMode(pinDT, INPUT_PULLUP);
    pinMode(pinSW, INPUT_PULLUP);
    pinMode(LED_BUILTIN, OUTPUT);
    digitalWrite(LED_BUILTIN, LOW);
    int a = digitalRead(pinCLK);
    int b = digitalRead(pinDT);
    lastState = (a << 1) | b;
    lastSW = digitalRead(pinSW);
    Serial.println(F("KY-040 Rotary Encoder Test (State Machine)"));
    setAliveDataPrinter(beaconData);
    initAliveBeacon();
}


void loop() {
    runAliveBeacon();
    // Rotary encoder state machine
    int a = digitalRead(pinCLK);
    int b = digitalRead(pinDT);
    int currState = (a << 1) | b;
    int idx = (lastState << 2) | currState;
    int8_t movement = enc_states[idx & 0x0F];
    if (movement != 0) {
        encoderValue += movement;
        if (DEBUG) {
            if (movement > 0) {
                Serial.print(F("Rotated CW, value: "));
                Serial.println(encoderValue);
            } else {
                Serial.print(F("Rotated CCW, value: "));
                Serial.println(encoderValue);
            }
        }
        Serial.print(F("Knob State: "));
        Serial.println(encoderValue);
    }
    lastState = currState;

    // Button
    int currentSW = digitalRead(pinSW);
    if (currentSW != lastSW) {
        delay(5); // debounce
        if (digitalRead(pinSW) == LOW) {
            Serial.println(F("Knob Button pressed"));
        } else {
            Serial.println(F("Knob Button released"));
        }
        lastSW = currentSW;
    }

    // Heartbeat
    unsigned long now = millis();
    if (now >= hbNextBeatDueMs) {
        bool on = (hbBeatIndex % 2 == 0) && (hbBeatIndex/2 < HB_FLASHES);
        digitalWrite(LED_BUILTIN, on ? HIGH : LOW);
        hbBeatIndex++;
        if (hbBeatIndex >= HB_CYCLE_BEATS) {
            digitalWrite(LED_BUILTIN, LOW);
            hbBeatIndex = 0;
            hbNextBeatDueMs = now + HB_CYCLE_PAUSE_MS;
        } else {
            hbNextBeatDueMs = now + HB_BEAT_MS;
        }
    }
}

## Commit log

2025-09-09 update firmware for buttons, sliders, and switches
2025-09-10 correct name of file
    [4_switches_module.ino]
2025-09-10 add build and upload scripts for arduino nanos
2025-09-10 testing sign of life message in button module
2025-09-10 fix for alive beacon on e-ink module
    [6_e-ink_display_module.ino]
2025-09-10 add test for identifying arduinos
2025-09-28 add cad files and print instructions
    [Blank_Module.stl, Box_Bottom.stl, Button_Box.stl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]
2025-09-29 add BOM and link to BOM from README
2025-09-29 adding pi zero and usb hubs to the bom calculation
2025-09-29 update firmware flashing instructions and add detailed setup guide for Raspberry Pi Zero W and arduino nanos
2026-01-26 Update BOM with new sections and items
    Added a section for Minimal Required Build without electronic instrumentation and included a new item for a Portable Battery Bank.
2026-01-26 Update printing instructions with solid model location
    Added location of solid model file for clarity.
2026-01-26 Fix case of task_box file name in instructions
    Corrected the file name case for the solid model in the printing instructions.
2026-03-27 Add devices/pi_sw directory with MQTT bridge and test scripts (#16)
    Adds the missing pi_sw directory referenced in devices/flashing_firmware.md.
    Files added:
    - mqtt_bridge.py: BusyBox MQTT bridge that discovers Arduino modules and publishes sensor data
    - test_aggregation.py: Test script for data aggregation
    - test_identify_arduinos.py: Test script for Arduino identification
    Closes #15
    [mqtt_bridge.py, test_aggregation.py, test_identify_arduinos.py]
2026-03-27 Add aloha + BusyBox data recording pipeline (#17)
    * Data aggregation (#8)
    * update comment
    * initial stab at data aggregation
    * increase publish interval for e-ink
    * add alive data printer
    * fix e-ink display
    * identify bugfix
    * identify bugfix
    * removing crappy changes
    ---------
    * Broadcast data (#9)
    * update comment
    * initial stab at data aggregation
    * increase publish interval for e-ink
    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
    [1_buttons_module.ino, 2_knob_module.ino, 3_sliders_module.ino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]
2026-04-10 add 3mf cad
    [Rotary_Text_Multicolor.3mf, Slider_Knobs_Multicolor.3mf, Slider_Text.3mf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]
2026-06-21 Update BOM with new E-Ink display and cost adjustment
    Added Waveshare 2.13inch E-Ink display HAT to BOM and updated total cost.
